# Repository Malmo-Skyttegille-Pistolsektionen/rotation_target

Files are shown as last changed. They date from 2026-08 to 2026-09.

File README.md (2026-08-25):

# Rotation Target

Software for running timed shooting programs on a rotating target system, built
by and for Malmö Skyttegille Pistolsektionen.

An ESP32-S3 board turns the targets face-on and edge-on to a shooting program
and plays the spoken range commands over an amplifier. A React web app — served
by the board itself over WiFi — starts and stops programs, follows the run live
over Server-Sent Events, and manages the stored programs and audio.

## ⚠️ SAFETY WARNING — READ BEFORE INSTALLING OR OPERATING

**This device moves steel on a live firing range, and it moves it on a timer.**
A target turns because a program said it was time, not because it can see who
is in front of it. It has no idea anyone is downrange.

- **The range's own safety rules and range commands govern the line. This
  software governs nothing.** A program running is not a range that is hot; a
  program stopped is not a range that is safe.
- **NEVER go downrange because the web app says the run has finished.** Confirm
  a cease-fire the way your range already requires — verbally, with firearms
  cleared and benched.
- **NEVER leave the device powered while people are forward of the firing
  line** unless your club has decided that is safe and knows what the targets
  do at power-up.
- **A target turning can injure somebody standing next to it.** Keep clear of
  the mechanism whenever the device is powered.

The targets rest **shown** at boot, deliberately: a target that turns of its own
accord when a board is powered is the failure this project is most concerned
with. That resting state can be changed to suit a target system wired the other
way round, but only over a USB cable, never from the web app — see
[Settings](https://malmo-skyttegille-pistolsektionen.github.io/rotation_target/settings/).

**Do not rely on this software to protect anyone.** It is a convenience for
running programs, not a safety device, and it has no interlock, no sensor, and
no way to know where people are.

**LIABILITY DISCLAIMER:** This project is provided as-is with absolutely no
warranty of any kind. The author(s) accept no responsibility or liability for
any injury, damage, or loss resulting from building, installing, modifying, or
operating this system. You build and use it entirely at your own risk.

---

## Documentation

Everything an operator needs is on the documentation site:

- **[Operator documentation](https://malmo-skyttegille-pistolsektionen.github.io/rotation_target/)**
  — wiring, connecting, running a program, settings, and what the status LED is
  telling you. This is the one to send a club member.
- **[Program editor](https://malmo-skyttegille-pistolsektionen.github.io/rotation_target/editor/)**
  — write and edit programs in a browser with **no device attached**, then
  download the file or open a pull request against this repository. Also useful
  for reading a shipped program without a board in front of you.
- **[Hardware and wiring](https://malmo-skyttegille-pistolsektionen.github.io/rotation_target/hardware/)**
  — what a target system has to do to work, the DB9 pinout, and the transistor
  that does the switching.

## Installing

Releases ship a pre-built firmware image; you do not need a toolchain to put it
on a board. See
[Connecting](https://malmo-skyttegille-pistolsektionen.github.io/rotation_target/connecting/)
for getting the device onto your network afterwards, and
[Settings](https://malmo-skyttegille-pistolsektionen.github.io/rotation_target/settings/)
for adapting a stock image to your own board — the target pin, its polarity,
the audio and LED pins and the device's name are all configurable on the
device, without rebuilding it.

## Target systems

- **[Eigenbrod TP2](https://eigenbrod-schiessanlagen.de/en/products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)**
  — what this was built against and what it runs on.

Nothing in the firmware is specific to that system. The board speaks no
proprietary protocol to the targets: it closes and opens **one circuit**, and
the target system's own electronics do the rest. Any system driven the same way
should work.

## Layout

| Directory | Holds |
|---|---|
| [`contracts/`](contracts/README.md) | The canonical API contract: OpenAPI for REST v2, AsyncAPI for SSE v2, the program schema |
| [`firmware/`](firmware/README.md) | The ESP-IDF firmware: target IO, audio, storage, REST + SSE server |
| [`webapp/`](webapp/README.md) | The React front end, embedded in the firmware's application image |
| [`resources/`](resources/README.md) | Shipped programs and audio clips flashed onto the device |
| [`docs/`](docs/) | The [decision log](docs/DECISIONS.md), [how releases are cut](docs/RELEASING.md), and the source of the documentation site |

## Contributing

Building, flashing, running it without a device, and the coding standards are
in [`CONTRIBUTING.md`](CONTRIBUTING.md).

## License

MIT — see the `LICENSE` file in each component directory.

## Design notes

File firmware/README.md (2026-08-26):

# Rotation Target Backend — ESP32 (ESP-IDF)

Native ESP-IDF firmware for Malmö Skyttegille Pistolsektionen's
[Eigenbrod TP2 rotation target system](https://eigenbrod-schiessanlagen.de/en/products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).
It runs shooting programs — turning the targets and playing the commands — and
serves the React webapp over REST and Server-Sent Events.

This is the ESP-IDF port of
[`rotation_target_backend_esp32_micropython`](https://github.com/Malmo-Skyttegille-Pistolsektionen/rotation_target_backend_esp32_micropython)
at its API v2 revision. Both speak the same contract; see
[`docs/adr/0001-esp-idf-port.md`](docs/adr/0001-esp-idf-port.md) for why the
port exists.

## Hardware

**ESP32-S3** with 16 MB flash and 8 MB PSRAM — an ESP32-S3-DevKitC-1 N16R8, or
the club's own REVOLVENOW Rev 1 board.

No pin is hardcoded: the target GPIO **and its polarity**, the status LED, and
the I2S pins are all `menuconfig` options, so a different board is a different
`sdkconfig` rather than a source edit.

See [`docs/HARDWARE.md`](docs/HARDWARE.md) for the wiring, the full option list,
the partition layout, and the esptool `--no-stub` quirk you will hit when
flashing these boards.

## Build, flash, test

```bash
git clone https://github.com/Malmo-Skyttegille-Pistolsektionen/rotation_target.git
cd rotation_target/firmware

idf.py set-target esp32s3          # FIRST clone only - see the warning below
idf.py menuconfig                  # optional: seed WiFi under "Rotation target backend"
idf.py build
idf.py -p /dev/ttyACM0 flash monitor
```

> ⚠️ **`idf.py set-target` and `idf.py fullclean` destroy `sdkconfig`** — the
> only copy of the WiFi credentials. Use **`idf.py reconfigure`** on a clone you
> have already built. Why, and how to keep the credentials out of the tree
> entirely, in [`CONTRIBUTING.md`](CONTRIBUTING.md).

> **`idf.py flash` uses esptool's stub loader, which fails on this board** and
> fails in a way that looks like bad flash. See
> [`docs/HARDWARE.md`](docs/HARDWARE.md) for the `--no-stub` invocation.

The shipped audio and programs live in the monorepo's sibling `resources/`
directory. The build reads them from there by default; point `RT_RESOURCES_DIR`
elsewhere to override.

The webapp is embedded in the **application image** when `../webapp/dist`
exists, so run `npm run build` in `webapp/` first — see
[*The seams*](../AGENTS.md#the-seams). Because it rides in the app slot, an OTA
updates it along with the firmware (#227); the shipped audio and programs are
still on the filesystem and still do not.

`idf.py flash` no longer touches what has been uploaded to the device: no image
is built for the `userdata` partition at all (#227), so there is nothing to
write over it. The app slot it writes carries the firmware, the web app and the
shipped audio together.

**`partitions.csv` is not a file to change casually** — a table change cannot
go out over the air and wipes NVS, so it costs a cable pass over every board.
See [*Changing the partition table*](CONTRIBUTING.md#changing-the-partition-table).

### WiFi

Credentials live in **NVS**, not in the firmware, so moving the device to a new
network does not need a rebuild. `idf.py flash` leaves the `nvs` partition
alone, so they also survive a firmware update.

If the device cannot join a network — out of the box, or because the range's
WiFi password changed — it brings up a **setup access point** and a captive
portal instead of sitting there unreachable:

1. Join `rotation-target-setup-XXXX` (password: `CONFIG_RT_SETUP_AP_PASSWORD`,
   default `rotationtarget`).
2. A setup page should open automatically; if not, browse to
   `http://192.168.4.1`.
3. Enter the network details. The device saves them and restarts.

The Kconfig `RT_WIFI_SSID`/`RT_WIFI_PASSWORD` values are only a first-boot
seed — leave them at the defaults and use the portal, or set them to skip it.
`sdkconfig` is gitignored either way, the same way the MicroPython backend kept
`wifi_credentials.py` out of git.

Once up, the device is at `http://rotation-target.local` (mDNS) or whatever
address it logs on boot.

### Host tests

The run state machine, the program JSON contract, the `stateUpdate` serializer
and the control lock all run on the build machine — no hardware, no sleeps:

```bash
cd host_test && cmake -B build && cmake --build build -j && cd build && ctest --output-on-failure
```

Add `-DRT_COVERAGE=ON` for gcov/gcovr coverage, or `-DRT_SANITIZE=ON` to build
the suites with ASan + UBSan:

```bash
cd host_test && cmake -B build-san -DRT_SANITIZE=ON && cmake --build build-san -j \
  && cd build-san && ctest --output-on-failure
```

CI runs both the plain and the sanitized build — the sanitizers force `-O1` and
change codegen, so a clean run of one is not evidence about the other. UBSan is
what catches signed-overflow in the duration and id arithmetic, which `-Wall`
cannot see.

Only `IDF_PATH` is needed (for ESP-IDF's copy of Unity), not the cross
toolchain.

### Lint

```bash
pre-commit run --all-files
```

`.clang-format` covers `main/`, `lib/rt_logic/` and `host_test/`. Vendored code
(`lib/psychic_http/`, `lib/arduinojson/`) and the repository's `resources/`
tree are excluded and must stay byte-identical to upstream — never reformat
them.

## API

[`docs/api-v2.md`](docs/api-v2.md) — REST under `/api/v2`, SSE at `/sse/v2`,
plus `GET /api/v2/diagnostics/info` for post-incident triage without a cable.
The canonical machine-readable contract is
[`../contracts/`](../contracts/README.md) — `openapi.yaml` for REST,
`asyncapi.yaml` for SSE, `program.schema.json` for the program document. A
change to any of them lands in the same PR as the firmware change it
describes.

## Layout

See [`docs/ARCHITECTURE.md`](docs/ARCHITECTURE.md) for the task model, the
locking rules and the storage layout.

| Path | Holds |
|---|---|
| `lib/rt_logic/` | Hardware-independent logic — the tested core |
| `lib/psychic_http/`, `lib/arduinojson/` | Vendored third-party |
| `main/` | The firmware: `io/`, `storage/`, `repositories/`, `executor/`, `net/` |
| `host_test/` | Unity suites for `lib/rt_logic/`, plus the CMake + CTest harness |
| `../resources/` | The shipped audio and programs (sibling directory) |

## Documentation

| Document | Covers |
|---|---|
| [`docs/api-v2.md`](docs/api-v2.md) | The REST + SSE contract, shared with the MicroPython backend |
| [`docs/HARDWARE.md`](docs/HARDWARE.md) | Boards, pin configuration, flashing, partitions |
| [`docs/ARCHITECTURE.md`](docs/ARCHITECTURE.md) | Task model, locking, storage layout |
| [`docs/QEMU.md`](docs/QEMU.md) | Running the firmware in the emulator, and what it does not emulate |
| [`docs/adr/0001-esp-idf-port.md`](docs/adr/0001-esp-idf-port.md) | Why this port exists |
| [`CONTRIBUTING.md`](CONTRIBUTING.md) | Workflow, tests, commit conventions |
| [`SECURITY.md`](SECURITY.md) | Threat model and reporting |

## Related

- [Frontend webapp](https://github.com/Malmo-Skyttegille-Pistolsektionen/rotation_target_frontend_webapp)
- [MicroPython backend](https://github.com/Malmo-Skyttegille-Pistolsektionen/rotation_target_backend_esp32_micropython)
- [Resources](https://github.com/Malmo-Skyttegille-Pistolsektionen/rotation_target_backend_resources) — programs, audio, API specs

## License

MIT. See [LICENSE](LICENSE).

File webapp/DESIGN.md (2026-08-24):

---
name: Rotation Target
description: Range-side control for a rotating pistol target — equipment that happens to have a screen.
colors:
  ink: "#111827"
  ink-body: "#213547"
  text-strong: "#374151"
  text-subtle: "#4b5563"
  text-muted: "#6b7280"
  surface: "#ffffff"
  surface-sunken: "#fafafa"
  surface-muted: "#f3f4f6"
  border: "#e5e7eb"
  border-strong: "#d1d5db"
  action: "#2563eb"
  action-deep: "#1d4ed8"
  accent: "#6366f1"
  accent-deep: "#4338ca"
  accent-tint: "#eef2ff"
  shown: "#16a34a"
  shown-tint: "#dcfce7"
  shown-text: "#14532d"
  go: "#15803d"
  go-deep: "#166534"
  stop: "#dc2626"
  stop-deep: "#b91c1c"
  stop-tint: "#fee2e2"
  stop-text: "#7f1d1d"
  warn: "#92400e"
  warn-tint: "#fef3c7"
  warn-border: "#fcd34d"
typography:
  # Eight steps, and every font-size in src/ is one of them. The ramp was
  # derived from what the app already shipped rather than imposed on it: the
  # sizes carrying real weight (0.85rem across 51 rules, 0.9rem across 37) were
  # simply never written down here, so the documented ramp and the CSS had
  # drifted apart in both directions.
  #
  # What was removed were the accidental near-duplicates - 0.7 beside 0.75,
  # 0.8 and 0.875 beside 0.85, and three components that each invented their
  # own `.title` size (1.05, 1.2, 1.25). Nothing moved by more than 0.15rem.
  display:
    fontFamily: "-apple-system, BlinkMacSystemFont, 'Segoe UI', Roboto, sans-serif"
    fontSize: "clamp(4.5rem, 24vw, 7rem)"
    fontWeight: 700
    lineHeight: 1
    fontVariation: "tabular-nums"
    usage: "The run screen's countdown, and nothing else."
  timer:
    fontFamily: "Inter, system-ui, Avenir, Helvetica, Arial, sans-serif"
    fontSize: "clamp(1.5rem, 5vw, 2rem)"
    fontWeight: 600
    lineHeight: 1.2
    usage: "The sticky timer that follows a run. Fluid on purpose - it has to stay readable on a phone held at arm's length and not dominate a laptop."
  headline:
    fontFamily: "Inter, system-ui, Avenir, Helvetica, Arial, sans-serif"
    fontSize: "1.5rem"
    fontWeight: 600
    lineHeight: 1.3
    usage: "Page headings, and the timeline's duration readout."
  title:
    fontFamily: "Inter, system-ui, Avenir, Helvetica, Arial, sans-serif"
    fontSize: "1.1rem"
    fontWeight: 600
    lineHeight: 1.4
    usage: "Section and card titles. The one step three components had each guessed differently."
  lead:
    fontFamily: "Inter, system-ui, Avenir, Helvetica, Arial, sans-serif"
    fontSize: "1rem"
    fontWeight: 500
    lineHeight: 1.5
    usage: "Controls that need to outweigh body text - a primary button, a card title in a dense list."
  bodyLarge:
    fontFamily: "Inter, system-ui, Avenir, Helvetica, Arial, sans-serif"
    fontSize: "0.95rem"
    fontWeight: 400
    lineHeight: 1.5
    usage: "Text the operator reads off a device at the range: table cells, form inputs, read-only values."
  body:
    fontFamily: "Inter, system-ui, Avenir, Helvetica, Arial, sans-serif"
    fontSize: "0.9rem"
    fontWeight: 400
    lineHeight: 1.5
    usage: "The default. Buttons, labels, most prose."
  small:
    fontFamily: "Inter, system-ui, Avenir, Helvetica, Arial, sans-serif"
    fontSize: "0.85rem"
    fontWeight: 400
    lineHeight: 1.5
    usage: "Supporting text under a control - hints, metadata, error detail. The most-used size in the app."
  label:
    fontFamily: "Inter, system-ui, Avenir, Helvetica, Arial, sans-serif"
    fontSize: "0.75rem"
    fontWeight: 600
    lineHeight: 1
    letterSpacing: "0.05em"
    usage: "Badges, group headings, tick labels. Anything set in caps."
rounded:
  sm: "4px"
  md: "6px"
  lg: "8px"
  xl: "12px"
  pill: "999px"
spacing:
  xs: "0.25rem"
  sm: "0.5rem"
  md: "0.75rem"
  lg: "1rem"
  xl: "1.5rem"
  xxl: "2rem"
components:
  button-default:
    backgroundColor: "{colors.surface}"
    textColor: "{colors.ink-body}"
    rounded: "{rounded.sm}"
    padding: "0.4rem 0.75rem"
    height: "var(--rt-control-height)"
    typography: "{typography.body}"
  button-primary:
    backgroundColor: "{colors.action}"
    textColor: "{colors.surface}"
    rounded: "{rounded.sm}"
    padding: "0.4rem 0.75rem"
    height: "var(--rt-control-height)"
  button-primary-hover:
    backgroundColor: "{colors.action-deep}"
    textColor: "{colors.surface}"
  button-destructive:
    backgroundColor: "{colors.surface}"
    textColor: "{colors.stop}"
    rounded: "{rounded.sm}"
    padding: "0.4rem 0.75rem"
  button-destructive-hover:
    backgroundColor: "{colors.stop-tint}"
    textColor: "{colors.stop}"
  button-go:
    backgroundColor: "{colors.go}"
    textColor: "{colors.surface}"
    rounded: "{rounded.lg}"
    padding: "0.75rem 1.5rem"
    height: "48px"
  button-stop:
    backgroundColor: "{colors.stop}"
    textColor: "{colors.surface}"
    rounded: "{rounded.lg}"
    padding: "0.75rem 1.5rem"
    height: "48px"
  input:
    backgroundColor: "{colors.surface}"
    textColor: "{colors.ink-body}"
    rounded: "{rounded.sm}"
    padding: "0.35rem 0.5rem"
    typography: "{typography.body}"
  badge-shown:
    backgroundColor: "{colors.shown-tint}"
    textColor: "{colors.shown-text}"
    rounded: "{rounded.md}"
    padding: "0 0.75rem"
    height: "36px"
  badge-hidden:
    backgroundColor: "{colors.stop-tint}"
    textColor: "{colors.stop-text}"
    rounded: "{rounded.md}"
    padding: "0 0.75rem"
    height: "36px"
  badge-neutral:
    backgroundColor: "{colors.surface-muted}"
    textColor: "{colors.text-strong}"
    rounded: "{rounded.md}"
    padding: "0 0.75rem"
    height: "36px"
---

# Design System: Rotation Target

## Overview

**Creative North Star: "Equipment, not software"**

This is range equipment that happens to have a screen. It is read standing up,
outdoors, in daylight, by someone who is about to run a live firing exercise and
has better things to look at than a user interface. Every visual decision
answers to that scene: grey by default, colour only where colour carries a
safety meaning, and type sized so the one number that matters can be read at
arm's length without walking to the phone.

The system is deliberately quiet. There is no brand expression competing for
attention, because the three signal colours — green, red, amber — have fixed
operational meanings and must be impossible to mistake for decoration. When a
surface looks plain here, that is the design working, not the design missing.

Density is medium and consistent: one control height for the whole app, one
breakpoint, one type ramp. The interface should feel like a well-labelled panel
of switches, where nothing moves unless the state moved.

**Key Characteristics:**

- Neutral greys carry structure; hue is reserved for state
- One control height (40px pointer, 44px touch) governs every row
- Numbers are tabular so a readout never reflows as it counts
- Flat at rest — depth is a response, not an ornament
- Legibility in daylight outranks visual interest, always

## Colors

A near-monochrome grey system with three signal hues that mean specific things,
plus a blue for the ordinary "do the thing" action.

### Primary

- **Signal Blue** (`#2563eb`): the ordinary confirming action — Save, Add,
  Create. It is the only blue in the system and never carries state meaning; a
  blue button is something you press, not something the target is doing.

### Secondary

- **Indigo** (`#6366f1`): "this is the one running." Marks the active series in
  the timeline and the time badge on the run board. Used as a border and a tint,
  never as a large fill.
- **Deep Indigo** (`#4338ca`): the same signal where it has to be readable as
  text — the active series title on its tinted ground.

### Tertiary

- **Amber** (`#92400e` on `#fef3c7`): the advisory register. Startup issues,
  "no delay armed", anything the operator should notice but which does not stop
  the exercise.

### Neutral

- **Ink** (`#111827`): the countdown readout, and nothing else. It is the
  highest-contrast value in the system and reserved for the highest-stakes
  number.
- **Body Ink** (`#213547`): default text.
- **Strong Grey** (`#374151`): badge text, table headers.
- **Muted Grey** (`#6b7280`): secondary and supporting text — the single most
  used colour in the app.
- **Border Grey** (`#e5e7eb`) / **Strong Border** (`#d1d5db`): dividers, card
  edges, control outlines.
- **Surface** (`#ffffff`), **Sunken** (`#fafafa`), **Muted** (`#f3f4f6`): the
  three grounds. Layering is done with these, not with shadow.

### Named Rules

**The Three Signals Rule.** Green means the target is shown, red means it is
hidden, amber means no delay is armed. No other element may use those hues for
any other purpose — not for a decorative accent, not for a chart, not for a
brand flourish. If a new state needs a colour and is not one of those three
things, it uses indigo or a grey.

**The One Family Rule.** The palette is the Tailwind scale, and only the
Tailwind scale. Two earlier families used to be mixed in — the Vite starter
purple (`#646cff`, never chosen, just the `npm create vite` default) and
Material's greens and reds on the timeline event boxes. Both are gone. The
purple mattered because it sits close enough to the accent indigo to look
intentional and far enough to look wrong beside it, which is the worst distance
for two colours to be.

**The Readable Signal Rule.** Signal colours are chosen for contrast, not for
brightness. White text sits on green-700 (`#15803d`), never green-600, because
white on green-600 measures 3.3:1 and fails AA. Any new coloured surface must
clear 4.5:1 for its text before it ships.

## Typography

**Body Font:** Inter (with system-ui, Avenir, Helvetica, Arial fallbacks)
**Readout Font:** the platform system stack (`-apple-system`,
`BlinkMacSystemFont`, `Segoe UI`, Roboto), used only for the countdown so the
digits render in the device's most familiar, most hinted numerals.

**Character:** plain, neutral, unstyled. The type is not doing expressive work;
it is doing legibility work. Weight and size carry the hierarchy, and there are
only three weights in the whole system.

### Hierarchy

- **Display** (700, `clamp(4.5rem, 24vw, 7rem)`, line-height 1): the countdown
  digits alone. Scales *up* with the viewport rather than down, and uses
  tabular numerals so the box does not resize as 10 becomes 9.
- **Headline** (600, 1.5rem): page titles.
- **Title** (600, 1.1rem–1.25rem): card and section headings, series titles.
- **Body** (400, 0.9rem): the workhorse. Table cells, descriptions, controls.
- **Label** (600, 0.75rem, 0.05em, uppercase): badge captions and field labels.
  Uppercase is the tell that something is a label and not content.

### Named Rules

**The Arm's Length Rule.** The countdown grows with the viewport instead of
shrinking with it. A phone held at the firing line is further from the eye than
a laptop on a desk, so `24vw` is the floor of the readout, not its ceiling.

**The Tabular Rule.** Any number that changes in place — countdown, elapsed
time, cumulative event time — is `font-variant-numeric: tabular-nums`. A
readout that jitters as its digits change is a readout nobody trusts.

## Layout

A single-column stack at every size, `1rem` page padding, `1rem` between cards.
Cards are full-bleed within that padding and do not have a max width; the
content is tables and timelines, both of which want the room.

**One breakpoint: 768px.** Below it, button rows become full-width columns,
event chips reflow, and tables switch to their compact presentation. Above it,
navigation tabs stop stretching to fill the bar. There is no tablet-specific
layout and there should not be one — the phone layout serves a tablet held in
two hands perfectly well.

**One control height.** `--rt-control-height` is the only global custom
property in the app: 40px for a mouse, 44px under `@media (pointer: coarse)` so
a gloved hand on the firing line gets the platform minimum tap target. Buttons,
selects, inputs and nav links all adopt it, which is what keeps a row of mixed
controls visually aligned.

Navigation is sticky at the top (`z-index: 30`). The run page is metres of
timeline on a phone, and the tabs have to stay reachable without scrolling back.

### Named Rules

**The No Nested Scroller Rule.** The document scrolls; panels do not. A flex
child with `overflow-y: auto` also computes `overflow-x: auto`, which silently
clipped the programs and audios tables off the right edge on a phone. Wide
content gets its own explicitly scrollable wrapper; layout containers get
`min-width: 0` instead.

## Elevation & Depth

**Flat at rest.** Surfaces separate by background tone and a hairline border,
not by shadow. This is a daylight interface: soft shadows wash out in sun and
cost more to composite on the device's embedded browser, while a 1px border at
`#e5e7eb` stays crisp in both.

Shadow is reserved for two jobs: things that genuinely float above the page,
and feedback that something responded to you.

### Shadow Vocabulary

- **Overlay** (`0 25px 50px -12px rgba(0, 0, 0, 0.25)`): modal dialogs only —
  the countdown and the confirmation. These really are above the page.
- **Response** (`0 2px 8px rgba(0, 0, 0, 0.1)`): hover and active feedback on
  an interactive card.
- **Lift** (`0 4px 12px rgba(0, 0, 0, 0.08)`): the running series. Neutral, not
  tinted — the indigo border already says "this is running"; a coloured halo
  under it only says "decorated".
- **Focus ring** (`0 0 0 3px <colour>/0.1`, or `outline: 2px solid #2563eb`
  with `2px` offset): keyboard focus. Never removed, never subtle.

### Named Rules

**The Flat-By-Default Rule.** A card gets a border, not a shadow. If you are
reaching for `box-shadow` on a resting surface, the answer is a tone change or
a border.

**The Neutral Elevation Rule.** Shadows are black at low alpha. A shadow tinted
to match its element's accent colour is decoration pretending to be depth.

## Shapes

A modest, consistent radius ramp and no other form language — no clipping, no
angles, no decorative geometry.

- **4px** — controls: buttons, inputs, nav links. The tightest radius, for the
  things you touch.
- **6px** — badges, chips, nested panels within a card.
- **8px** — cards and control boards.
- **12px** — modal dialogs, the largest surface and the largest radius.
- **999px** — pills, used sparingly for count indicators.

Borders are 1px for structure and 2px when the border itself is the signal (a
state badge, the active series).

### Named Rules

**The Side-Tab Ban.** No thick coloured border on one edge of a card. It is the
most recognisable tell of machine-generated UI, and this system says "warning"
with a tinted ground and a full hairline border instead.

## Components

### Buttons

- **Shape:** tight radius (4px), `--rt-control-height` tall, `0.4rem 0.75rem`
  padding, never wrapping (`white-space: nowrap`).
- **Default:** white ground, `#ccc` border, body text. The neutral majority.
- **Primary:** Signal Blue fill (`#2563eb`), white text, matching border;
  deepens to `#1d4ed8` on hover. One per view, at most.
- **Destructive:** white ground with a red border and red text (`#dc2626`),
  filling to `#fee2e2` on hover. Destructive actions are outlined, not filled —
  a solid red button is too easy to hit by accident on a touch screen.
- **Go / Stop (countdown only):** the two large 48px-tall filled buttons in the
  countdown dialog, green-700 and red-600, full-width on a phone. These are the
  only filled signal-coloured buttons in the app.
- **Focus:** `outline: 2px solid #2563eb` at `2px` offset on `:focus-visible`,
  on every interactive element without exception. The editor is driven from the
  keyboard as much as the mouse.

### Badges

- **Style:** 36px tall, 6px radius, `0 0.75rem` padding, a 2px border and a
  tinted ground, with an uppercase 0.75rem label beside the value.
- **Shown:** `#dcfce7` ground, `#16a34a` border, `#14532d` text.
- **Hidden:** `#fee2e2` ground, `#fca5a5` border, `#7f1d1d` text.
- **Time:** `#eef2ff` ground, `#6366f1` border, `#312e81` text.
- **Neutral:** `#f3f4f6` ground, `#e5e7eb` border, `#374151` text.

### Cards / Control Boards

- **Corner:** 8px. **Ground:** white on the page's `#fafafa`.
- **Border:** 1px `#eee`–`#e5e7eb`. **Shadow:** none at rest.
- **Padding:** `1rem`, with a `0.75rem` header rule above the content.

### Inputs

- **Style:** white ground, 1px `#ccc` border, 4px radius, `0.35rem 0.5rem`
  padding, `font: inherit` so they never drift from the body face.
- **Labels:** 0.75rem uppercase, stacked above the field with a `0.2rem` gap.
- **Focus:** the same 2px blue outline as buttons.

### Timeline (signature component)

The run page's series view is the one component with real domain personality.
Events render as compact chips — duration, command and cumulative time on one
line — reflowing four to five per row on a phone. The active series takes a 2px
indigo border and a neutral lift; the active event takes an indigo ring.

There is a time-scaled mode as well, but proportional widths are the wrong
default on a phone: a 1-second event inside a 30-second series is 3.3% of the
width, which is 11px at 390px wide. Auto mode chooses chips at narrow widths
for that reason.

### Dialogs

- **Shape:** 12px radius, `min(90vw, 420px)` wide, no border, the Overlay
  shadow.
- **Backdrop:** `rgba(0, 0, 0, 0.5)` with a 2px blur.
- **Content:** centred column, `2rem` padding (`1.5rem` on a phone), `1rem` gap.

## Do's and Don'ts

### Do:

- **Do** reserve green, red and amber for target shown, target hidden, and no
  delay armed. Anything else that needs colour uses indigo or a grey.
- **Do** put every interactive control at `var(--rt-control-height)` so mixed
  rows line up and touch targets stay at 44px on a phone.
- **Do** use `font-variant-numeric: tabular-nums` on any number that updates in
  place.
- **Do** give every focusable element a visible `:focus-visible` outline —
  2px solid `#2563eb`, 2px offset.
- **Do** check 4.5:1 contrast for text on any new coloured ground before
  shipping it. This system has already had ten failures found and fixed.
- **Do** give wide content (tables, timelines) its own scrollable wrapper
  rather than letting a layout container scroll.

### Don't:

- **Don't** put a thick coloured border on one side of a card.
- **Don't** put a resting shadow on a card. Use a border and a tone change.
- **Don't** tint a shadow to match its element's colour.
- **Don't** add `overflow-y: auto` to a flex layout container; it computes
  `overflow-x: auto` too and will clip content off the right edge.
- **Don't** put white text on green-600 (`#16a34a`) — 3.3:1. Use green-700.
- **Don't** introduce a fourth button style. There are four, and twelve files
  already redefine them; the next one should reuse, not add.
- **Don't** scale the countdown down on small screens. It is read from further
  away there, not closer.

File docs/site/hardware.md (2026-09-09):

# Hardware and wiring

This is what a target system has to be, electrically, before a board can drive
it — the thing a club member setting up a second device needs before anything
else on this site is useful.

## The interface: one circuit

The board does not speak any target system's proprietary protocol. It closes
and opens **one circuit**, over a DB9 connector, and the target system's own
electronics do the rest.

| DB9 pin | Function |
|---|---|
| 2 | Target control — shorted to ground to actuate the target system |
| 5 | Ground — the common return for pin 2 |

Electrically, the board does not close that circuit itself — a GPIO pin
supplies only tens of milliamps and should not meet the target system's
voltage directly. A transistor does the switching instead:

```mermaid
flowchart LR
    subgraph ESP["ESP32-S3"]
        GPIO["GPIO5"]
        GND["GND"]
    end

    R["1 kΩ"]
    Q["BC547B<br/>NPN · 45 V · 100 mA"]

    subgraph TS["Target system (DB9)"]
        P2["pin 2 — target control"]
        P5["pin 5 — ground"]
    end

    GPIO --> R --> Q
    Q -- collector --> P2
    Q -- emitter --> GND
    GND --- P5
```

A GPIO pin drives a 1 kΩ resistor into the base of a **BC547B** NPN
transistor, which does the actual switching. That transistor is rated
**45 V and 100 mA**, and it offers no galvanic isolation. Anything a target
system asks for beyond those limits — a mains-level signal, or an inductive
load like a relay coil — needs a relay or an opto-isolator of its own between
the DB9 connector and the load; it cannot be wired to pin 2 directly.

## What a target system has to do to work

Nothing in the firmware is specific to any one target system — it was built
against the [Eigenbrod TP2](https://eigenbrod-schiessanlagen.de/en/products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), but anything driven
the same way should work.

| Requirement | Why |
|---|---|
| Be actuated by a **contact closure** — two terminals shorted together | That is the entire interface. A system expecting a serial protocol, a proprietary bus or a mains signal needs hardware in between |
| Be **level-driven**, not pulse-driven | The firmware holds the line in one state for the length of an event. A system that toggles on each pulse would move on both edges |
| Have **two positions** — face-on and edge-on | The program vocabulary is show and hide. There is no intermediate angle to command |
| Take **one control line per group of targets you want to move together** | Each line is a *bank*. A bank is one contact closure and moves as one; a device drives up to eight |
| Be safe sitting **face-on** with no power | The targets rest face-on and stay there at boot, deliberately: somebody may be downrange when a board is powered, and a target that turns on its own can injure them |

## Target banks

A **bank** is one control line: one GPIO, one transistor, one DB9 circuit,
moving every target wired to it together. A device drives between one and
eight of them, lettered by position — **A, B, C…** — and A is the one the
diagram above shows. A club with one line of targets has bank A and nothing
else, which is what every device shipped so far is.

Banks exist so a range can be exposed a lane at a time: three lanes on three
banks can be shown one after another from a single program, where one line can
only turn all three at once.

Each bank is separate hardware. It needs **its own GPIO** and its own
transistor, and it carries **its own polarity** — whether a low level shows it —
because the resting state that has to be safe is a property of that bank's
wiring, not of the device. Adding one is therefore soldering first and
configuration second: wire the line, then add the bank in
[Expert mode](expert-mode.md) with the pin you wired it to, a name your
operators will recognise (`Vänster`, `Bana 3`), and the polarity that leaves it
resting where it should. The device adopts a new bank at its next restart.

Where the targets rest at boot is **one setting for every bank**, changed on
the serial console only: it protects somebody standing downrange, and that is
not a per-bank question.

Which level shows the targets, and the rest of the pin assignment, is a
configuration setting rather than a build setting now — but it is still decided
when a device is set up, not per range day. Full wiring detail, including the
supported boards and their `menuconfig` options, is in
[`firmware/docs/HARDWARE.md`](https://github.com/Malmo-Skyttegille-Pistolsektionen/rotation_target/blob/main/firmware/docs/HARDWARE.md)
in the repository.

**Optional peripherals**, each independently switchable off at build time: the
audio DAC that plays the range commands, and the [status LED](status-led.md).
A target that only turns, with no audio, is a supported configuration.

<!-- TODO: a photograph of the DB9 connector and the transistor as actually wired -->

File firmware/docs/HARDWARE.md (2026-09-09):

# Hardware

## Supported boards

The firmware targets **ESP32-S3** with 16 MB flash and 8 MB PSRAM. Two boards
are in use:

| Board | Module | Notes |
|---|---|---|
| ESP32-S3-DevKitC-1 N16R8 | ESP32-S3-WROOM-1 N16R8 | Development board. Has an onboard WS2812 on GPIO48. |
| REVOLVENOW Rev 1 | ESP32-S3-WROOM-1 N16R8 | The club's own board (open source hardware). Trigger outputs with selectable 3.3 / 5 / 12 V rails, Ethernet section, hand-fitted PCM5102A audio breakout on the Rev 1 prototypes. No onboard WS2812. |

Confirmed against real silicon with `esptool flash-id`: ESP32-S3 (QFN56)
rev v0.2, 16 MB **quad** flash at 3.3 V, embedded **8 MB octal** PSRAM. The
"flash type: quad" the eFuse reports is about the flash only — the R8's PSRAM
is octal, which is why `sdkconfig.defaults` sets `CONFIG_SPIRAM_MODE_OCT`.
Getting that backwards leaves PSRAM undetected at boot rather than failing
loudly.

## Configuration

**No pin is hardcoded.** Everything is a `menuconfig` option under
**Rotation target backend → Hardware**, so a different board is a different
`sdkconfig`, not a source edit.

| Option | Default | Meaning |
|---|---|---|
| `RT_TARGET_GPIO` | 5 | Drives the transistor that turns **bank A** |
| `RT_TARGET_ACTIVE_LOW` | y | Whether **low** shows bank A |
| `RT_RGB_LED_ENABLED` | y | Board has an addressable WS2812 |
| `RT_RGB_LED_GPIO` | 48 | Its pin |
| `RT_AUDIO_ENABLED` | y | Board has an I2S DAC |
| `RT_I2S_PORT` | 0 | I2S peripheral number |
| `RT_I2S_BCK_GPIO` | 10 | Bit clock |
| `RT_I2S_WS_GPIO` | 12 | Word select (LRCK) |
| `RT_I2S_DOUT_GPIO` | 11 | Data out → the DAC's DIN |

Defaults are the wiring the MicroPython backend used on this hardware
(`src/backend/config.py` in that repository). Note its "ESP32-C6" comments are
stale — the pin numbers beside them are correct, the chip name is not.

> ⚠️ **`RT_TARGET_ACTIVE_LOW` is a safety setting, not a preference.** It says
> which level *shows* the targets. On the prototype the GPIO drives a BC547B
> whose low state opens the connection. A board that buffers, inverts, or
> switches a relay directly needs it off — and if it is wrong, the boot state in
> `targets::init()` is inverted, so the targets face away when they should be
> face-on (D-31).

### Target banks

A device drives 1 to 8 banks, called **A** to **H** (D-41). Kconfig seeds bank A
only — a second bank is something a device is *told about*, over the API or the
serial console, and it lives in NVS beside the rest of the hardware
configuration. Every bank has its own pin, its own polarity and a display name.

| Bank | Suggested pin | Note |
|---|---|---|
| A | 5 | The stock target pin; `RT_TARGET_GPIO` |
| B–H | 6, 7, 8, 9, 13, 14, 15 | Adjacent on the DevKitC-1 header, all free |

Nothing forces those seven — any pin the validator accepts will do. They are
listed because they are contiguous on the header and none of them clashes with
the stock LED or I2S wiring.

### Pins the configuration refuses

`rt::validate()` refuses these outright rather than warning, because the
recovery from getting one wrong is a USB cable and a reflash.

| Pins | Why |
|---|---|
| 0, 3, 45 | Strapping — latched at reset; the board simply does not come up |
| 19, 20 | USB Serial/JTAG D-/D+ — the recovery path |
| 22–25 | Absent from the ESP32-S3 package |
| 26–32 | In-package SPI flash and PSRAM |
| **35–37** | The **octal** PSRAM's extra data lines on the N16R8 |
| **43, 44** | UART0 — the serial console |
| 46 | Input-only on many modules, so it cannot drive anything |

35–37 are the ones to know about; D-41 records why they were missed. That
leaves 22 output-capable pins after the stock five (target 5, LED 48, I2S
10/11/12) — comfortably more than eight banks need.

Disabling `RT_RGB_LED_ENABLED` or `RT_AUDIO_ENABLED` compiles the driver out
entirely rather than failing at runtime. A target that only turns, with no
audio, is a supported configuration: programs still run and the API still lists
clips, they simply do not play.

## Wiring (prototype)

| ESP32 pin | Connects to | Function |
|---|---|---|
| GPIO5 | DB9 pin 2, via 1 kΩ into a BC547B | Target control (bank A) |
| GND | DB9 pin 5 | Common ground |
| GPIO10 / GPIO12 / GPIO11 | PCM5102A BCK / LRCK / DIN | I2S audio |
| GPIO48 | onboard WS2812 (devkit only) | Status LED |

```mermaid
flowchart LR
    subgraph ESP["ESP32-S3"]
        GPIO["GPIO5"]
        GND["GND"]
    end

    R["1 kΩ"]
    Q["BC547B<br/>NPN · 45 V · 100 mA"]

    subgraph TS["Target system (DB9)"]
        P2["pin 2 — target control"]
        P5["pin 5 — ground"]
    end

    GPIO --> R --> Q
    Q -- collector --> P2
    Q -- emitter --> GND
    GND --- P5
```

The status LED, where fitted: **blinking red** while joining a network, **solid
red** once it has given up, **yellow** on the network but not serving yet,
**green** serving, **blue** on the setup portal's own access point. Yellow is
milliseconds wide on a healthy boot, so a device sitting on it means the network
is fine and the HTTP server is not.

## Flashing

### Large reads need `--no-stub`

**esptool's stub fails on `read-flash` above roughly 3 MB per transfer.** It
dies with `Packet content transfer stopped`. Measured on the DevKitC-1 over the
native USB port, esptool 5.3.1, reading from `0x0`:

| Transfer | Stub | Result |
|---|---|---|
| 1 MB | yes | works |
| 2 MB | yes | works |
| 3 MB | yes | works |
| 4 MB | yes | **fails** |
| 8 MB | yes | **fails** |
| 16 MB | yes | **fails** |
| 16 MB | `--no-stub` | works |

It is the *size* that decides it, not the address: where it dies is wherever
the transfer had got to. The threshold sits between 3 MB and 4 MB.

**The stub does not return bad data — it fails, or it is correct.** A 1 MB stub
read was compared byte for byte against the same range of a `--no-stub` dump of
the whole chip. The only differences were inside `nvs`, because esptool resets
the board between reads and the firmware writes NVS on boot. Everything else
matched exactly.

**So most work does not need `--no-stub`,** and the stub is roughly 15x faster
(1 MB in 5.9 s). Reach for it when reading at full-flash scale — taking a
backup image of a board, for instance:

```bash
esptool --port /dev/ttyACM0 --no-stub --baud 921600 \
  read-flash 0x0 0x1000000 flash_full_16MB.bin
```

**Writes are a separate question and are not covered by the numbers above.**
`write-flash` with the stub was measured good at 1.1 MB and at 10 MB on
2026-08-24, hash-verified, so `idf.py flash` is fine. A full 16 MB write with
the stub has not been tested. Until it is, a restore of a whole-chip image is
the one write worth doing with `--no-stub`, on the grounds that it runs when
something has already gone wrong.

```bash
# flash arguments are printed at the end of `idf.py build`
python -m esptool --chip esp32s3 --port /dev/ttyACM0 \
  --before default-reset --after hard-reset \
  write-flash --flash-mode dio --flash-freq 80m --flash-size 16MB \
  0x0 build/bootloader/bootloader.bin \
  0x8000 build/partition_table/partition-table.bin \
  0x1d000 build/ota_data_initial.bin \
  0x20000 build/rotation_target_backend.bin
```

**A failed large read presents exactly like a bad flash sector and is not one.**
Running the same read with and without `--no-stub` is the test that tells them
apart; chasing it as failing hardware, or as a cable problem, wastes a lot of
time.

> **This section has been wrong before.** It previously claimed the threshold
> was "about 256 KB" and that 512 KB and 1 MB reads failed — they do not. The
> rule survived unexamined because "always pass `--no-stub`" was cheap to obey,
> so nobody re-derived it. If you change these numbers, say what you measured
> and when.

### Ports

The boards expose two USB-C sockets. The **native USB-Serial/JTAG** one is USB
vendor `303a`; the **UART bridge** is `10c4` (CP2102) or `1a86` (CH343).

**Both can enumerate as `/dev/ttyACM*`** — the CH343 is a CDC device too — so
the device name does not tell them apart. The vendor does:

```bash
udevadm info -q property -n /dev/ttyACM0 | grep ID_VENDOR_ID
# 303a = native USB-Serial/JTAG
# 1a86 / 10c4 = UART bridge
```

**Which socket matters, and not symmetrically:**

| | native USB (`303a`) | UART bridge (`1a86`/`10c4`) |
|---|---|---|
| `ESP_LOG` output | yes | yes |
| **The interactive console** | **yes** | **no** |
| Flashing | yes | yes |
| Large `read-flash` | needs `--no-stub` | fine |

The console is the asymmetric one and it catches people out. `console.cpp`
writes with `usb_serial_jtag_write_bytes()`, so **the `rt>` prompt exists only
on the native USB socket.** On the UART bridge the log output still streams,
which makes the port look right — but every command typed there is silently
ignored. That covers `boot-targets` (#144), `wifi-scan` and `wifi-info`.

If a documented serial-only command appears to do nothing, check the vendor ID
before checking anything else.

With two boards connected, tell them apart by MAC — the kernel puts it in the
device name:

```
/dev/serial/by-id/usb-Espressif_USB_JTAG_serial_debug_unit_30:ED:A0:A8:AB:78-if00
```

While a board still runs MicroPython, its firmware claims the USB CDC endpoint
after every hard reset, so back-to-back esptool invocations are less reliable
than one long call; `--before no-reset --after no-reset` holds it in the
bootloader. This firmware does not use native USB and does not do that.

### Reflashing discards uploaded programs and audio

`idf.py flash` rewrites the LittleFS image, so anything a club uploaded to the
device goes with it. Use `idf.py app-flash` to update only the firmware and
leave the uploaded files alone.

The `nvs` partition survives either way, so the WiFi credentials and the
hardware configuration outlive a reflash.

## Partitions

16 MB, `partitions.csv`:

| Partition | Offset | Size | Purpose |
|---|---|---|---|
| `nvs` | 0x9000 | 24 K | WiFi credentials, calibration |
| `otadata` | 0xF000 | 8 K | Which OTA slot is active |
| `ota_0` | 0x20000 | 3 M | Firmware (~1 MB used) |
| `ota_1` | 0x320000 | 3 M | Second OTA slot |
| `storage` | 0x620000 | 9.75 M | LittleFS: shipped + uploaded audio and programs |
| `coredump` | 0xFE0000 | 128 K | Crash dump |

Sums to exactly 16 MB. Repartitioning a deployed device means a full erase, so
the slots are deliberately larger than currently needed.

OTA rollback is enabled and the app self-validates at the end of `app_main`,
but there is **no OTA endpoint yet** — the only way to write the second slot
today is `idf.py app-flash` over USB.

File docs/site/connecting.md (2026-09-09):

# Connecting

The board serves its own web app — there is nothing to install. But you can
only open it once the device is **on a network you are also on**, so that comes
first.

## Start with the LED

The [status LED](status-led.md) tells you which of two situations you are in,
before you try any address:

| LED | Situation | Go to |
|---|---|---|
| **Green** | On a network and serving | [Finding the device](#finding-the-device) |
| **Blinking red** | Still trying to join | Wait — it blinks once per attempt, about every 2.4 s |
| **Blue** | Gave up, and is now offering its own network | [The setup portal](#the-setup-portal) |
| **Solid red** | Out of attempts and not offering one either | See [Troubleshooting](troubleshooting.md) |

A device that has never been configured, or that has been moved to a site whose
WiFi it does not know, comes up **blue**. There is no address to find yet — the
network it should join does not exist from its point of view.

## The setup portal

A **blue** LED means the device is running a small access point of its own. Its
name follows the pattern `rotation-target-setup-XXXX`, where `XXXX` is unique to
that device, so two boards on the same site can be told apart.

Join that network from a phone or tablet. It is normally password-protected —
ask whoever set the device up if joining does not prompt for one. Once joined, a
captive-portal page should open by itself; if it does not, browse to
`http://192.168.4.1`.

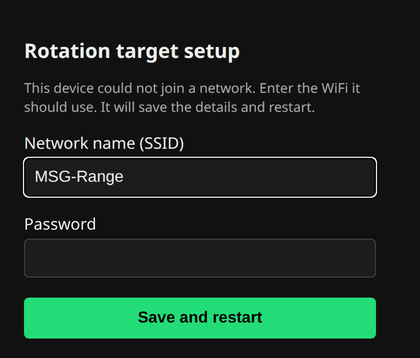
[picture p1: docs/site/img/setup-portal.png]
The setup portal, as it appears on a phone that has joined the device's own network


Enter the network name and password the device should use.

!!! important "Press the button on the device before saving"

    The device will not accept network details until somebody presses its
    **BOOT** button — the small button next to the USB sockets, marked `BOOT` or
    `FLASH` on some boards. Press it, then press **Save and restart**.

    If you save without pressing it first, the page says so and nothing is
    stored; press the button and save again.

    **Why:** the setup network's password is the same on every device and this
    project's source is public, so being *on* that network does not prove much.
    Pressing the button proves somebody is standing at the device — which is
    exactly what cannot be done from a car park. Without it, anyone in radio
    range of a device that has lost its network could point it at a network of
    their choosing.

    The press is good for about a minute, so there is no rush, and a press
    nobody remembers making cannot authorise anything later.

Once saved, the device restarts and joins that network the normal way — the LED
goes blinking red, then green.

From here it is on your network, and the rest of this page applies.

## Moving the device to a different network

If the device can no longer reach the network it knows — the club changed its
WiFi, or the board has been taken somewhere else — it gives up after about ten
seconds and raises the setup portal by itself. Nothing to do: wait for **blue**
and [configure it from there](#the-setup-portal).

The other case is: **the network it knows still exists, and you want it on a
different one anyway.** The device joins ours quite happily and never offers
the portal, so there is nothing to configure it through.

For that, use [Expert mode](expert-mode.md#wifi) — press the device's BOOT
button three times within ten seconds, and the web app offers the same form the
setup portal does. Saving stores the network; the device moves onto it when you
press [**Restart to apply**](expert-mode.md#restart-to-apply), and keeps
everything else: its programs, its clips, and its hardware settings.

**The ten-second hold below is the bigger hammer**, and it is now needed only
for handing a board to another club, or for a board that has to forget the
network built into its firmware. It throws away more than the network.

To do that, **hold the BOOT button for ten seconds**.

| While you hold | LED | Meaning |
|---|---|---|
| 0–3 seconds | unchanged | Nothing has happened yet |
| after 3 seconds | **white** | It is counting. Let go now and nothing is changed |
| after 10 seconds | restarts | Done |

It comes back up **blue**, offering its setup portal, exactly like a board that
has never been configured.

!!! warning "What a ten-second hold erases"

    - **Every network it knows**, including the one built into its firmware —
      which is the point, otherwise it would simply rejoin ours.
    - **Its hardware settings**: pin numbers, hostname and display name go back
      to the defaults, so it will answer to `rotation-target.local` again.

    **Your programs and audio clips are kept.** Anything uploaded to the device
    stays on it, including through a change of owner — that is a separate thing
    from which network it is on, and it may be the only copy.

If you have a USB cable and a serial terminal, `factory-reset` at the device's
console does the same thing and says what it is about to do first.

## Finding the device

Join the same WiFi the device is on, then open its address.

It advertises itself over mDNS, so on most phones, tablets and laptops the
address is just its hostname:

```
http://rotation-target.local
```

If that name does not resolve — some routers and most guest networks block
mDNS — find the device's IP address instead, for example from the router's
client list, and open `http://<that address>` directly. The address is also
shown on the app's own Settings page, beside the server URL, which is the
easiest way to read it out to somebody else once you are in.

The app opens on the Run page:

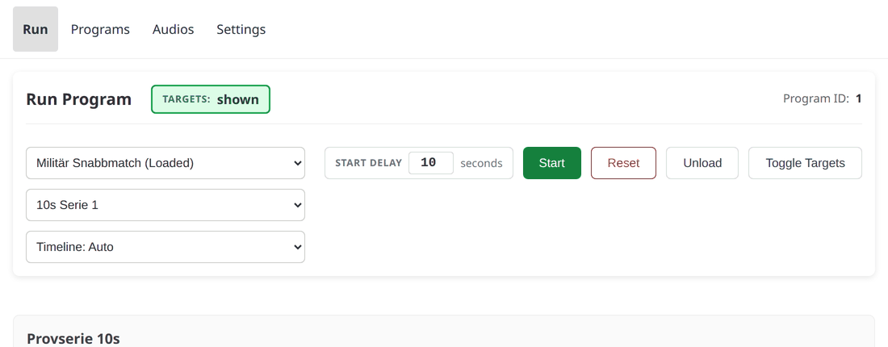
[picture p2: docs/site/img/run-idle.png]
The Run page with nothing loaded


## Editing programs without a device

Programs can also be written on a laptop with no board involved at all, using
the [program editor on the web](https://malmo-skyttegille-pistolsektionen.github.io/rotation_target/editor/)
— see [Writing your own program](writing-a-program.md).

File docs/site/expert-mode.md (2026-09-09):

# Expert mode

Everything that can stop the device working lives here, and nothing else does.

Most clubs never open this page. The settings on it are the ones set once, when
a board is first put together or moved somewhere new — and getting one wrong
does not produce a warning, it produces a device that no longer answers.

## Getting in

**Press the BOOT button on the device three times within ten seconds.** It is
next to the USB sockets and may be marked `FLASH`. An **Expert mode** tab
appears in the web app and stays for five minutes; press three times again for
a fresh five.

Three presses rather than one so it cannot happen by accident, and a button
rather than a password because the thing being established is that **somebody
is standing at the device**. That is not something anyone can do from across
the range, at any distance, with any credential — which is the whole point.

!!! note "It will not open during a run"

    A program that is running holds the window shut. Reconfiguring the machine
    and operating it are different jobs, and these settings only take effect
    when the device restarts anyway. Stop the run first.

If the tab is not there, nobody has pressed the button recently. If it vanishes
while you are typing, the five minutes ran out — press three times again and
carry on.

## Restart to apply

**Nothing on this page takes effect until the device restarts**, and nothing on
it restarts the device by itself. Each section has a plain **Save**, which
stores the change; the device carries on doing what it was doing.

**Restart to apply** appears beside the *Expert mode* heading whenever the
device is holding a setting it is not yet running, and applying everything is
one press of it. So a pin, the hostname and the network can all be corrected in
the same sitting, and the device goes down once instead of three times.

!!! note "The page loses contact while it restarts"

    A few seconds, then reload. If a network change was among what you saved,
    reload at the device's name on the *new* network — and if it cannot join
    that one, it raises its own setup network (`…-setup-XXXX`) and waits there,
    which is [the way back](connecting.md#the-setup-portal) rather than a fault.

The button stays after the five-minute window lapses, and the sections do not:
what the window authorises is the *change*, and this only applies one already
made. **Settings** says the same thing in one line, so somebody who did not make
the change still finds out about it.

It will not restart during a run. Stop the program first.

## WiFi

Which network the device joins. The same form as
[the setup portal](connecting.md#the-setup-portal), because it is the same job:
pick a network from the list, or type the name of one the scan did not find,
and give the password.

**This is the answer to "the network it knows still exists, but I want it
somewhere else."** Before this existed, the only way was to erase everything
the device knew and let it fall back to its setup portal — see
[moving the device](connecting.md#moving-the-device-to-a-different-network),
which is still the route when the board cannot reach *any* network it knows.

**Save** stores the network and nothing more: the device stays on the network
this page is served over, so a mistake here is still fixable from the page that
made it. It moves when you press **Restart to apply**, which is where the
warning above about losing contact applies.

Nothing you have uploaded is affected. Programs and clips are a separate thing
from which network the device is on.

**Rescan networks** runs a fresh scan. It takes a couple of seconds during
which the device's radio is off its own channel, so the page may pause — that
is the scan, not a fault.

**For a hidden network**, leave the list alone and type the name. A hidden
network never appears in a scan, so the list cannot offer it.

## Hardware

Which pins this board uses, what it calls itself, and how it joins the network.
Wrong values here are the ones whose way back is a USB cable:

- A **wrong pin** drives nothing, and one of the pins the device refuses would
  stop it booting at all — which is why it refuses them.
- A **wrong hostname** changes the name the device answers to, so the web app
  stops being reachable at `rotation-target.local`. Worse than a wrong pin,
  which at least leaves the app up to fix it from.

**Nothing here takes effect until the device restarts**, and the page says so
when a saved value is not yet in use — then **Restart to apply** at the top of
the page. A change that appears to have done nothing is how somebody ends up
reflashing a working device.

### The target banks

**Targets** is a table, one row per [bank](hardware.md#target-banks) — one
control line each, lettered by position:

| Column | What it is |
|---|---|
| **Bank** | The letter, A first. It is the row's position, not a stored value, so removing a bank re-letters the ones after it |
| **Name** | What operators see on the Run page — `Vänster`, `Bana 3`. Display only, at most 16 characters, and may be left empty |
| **GPIO** | The pin this bank's transistor is wired to. Every bank needs its own, distinct from the LED's and the three audio pins |
| **Shown when low** | Whether a low level shows *this* bank. Per bank, because the resting state that has to be safe is a property of that bank's wiring |
| **Pad now** | The level actually on the pin, read back rather than remembered. It answers "is the firmware driving this" without a multimeter |

**Add bank B** appends the next letter, up to eight — the most this firmware
drives. A new row starts with **no GPIO**; Save waits until every row has one,
because GPIO 0 is a pin the device refuses and a row cannot be left holding a
value that would come back an error.

Only the **last** bank can be removed, and **bank A never can**: the letter is
the position, so removing B on a four-bank device would silently re-aim C and D
at the wrong lanes. Remove them from the end and add them back.

A row whose values differ from the compiled defaults is marked **changed**, the
same way every other setting on this page is, so **Reset to defaults** says
what it would undo.

A bank you add is only configuration; the line still has to be wired, and the
device adopts the new count when it restarts.

**Where the targets rest at boot** is shown but not editable, and it is **one
setting for every bank**. Which position is safe at rest is a property of the
target system, so it has to be configurable — but it is also what protects
somebody standing downrange when a board is powered, so it changes only from
the serial console with a cable attached.

## Troubleshooting

One zip file holding the device's own details and, if it has crashed, the crash
dump — the thing to attach to a message when a board has come back from a range
day behaving oddly.

!!! warning "A crash dump can contain the WiFi password"

    It is a copy of the device's memory at the moment it failed. Send it to
    somebody you would tell the password to.

That is why it is behind the button press, and it is *only* behind the button
press: [the control lock](settings.md#control-lock) does not block it. Collecting a
fault report is a read, it interferes with nobody, and the person most likely
to want one during a competition is whoever is not driving.

[Sending a fault report](troubleshooting.md#sending-a-fault-report) has the
steps.

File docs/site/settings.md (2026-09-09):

# Settings

The Settings tab holds two different kinds of thing, and it is worth knowing
which is which before changing anything:

- **Browser settings** live in the browser you are using. Another phone or
  tablet at the same range keeps its own, and clearing site data resets them.
- **Device settings and readouts** come from the board itself, and are the
  same for everyone looking at it.

| Section | Kind | What it is |
|---|---|---|
| Server Base URL | browser | Which device this browser talks to |
| Address | device | The address the device says it is reachable on |
| Control lock | device | Whether control is open to everyone or needs a login |
| Start delay | browser | Seconds counted down before a run starts |
| Startup Issues | device | What the device could not read when it booted |
| Storage | device | How much room the flash partitions have |
| WiFi | device | Which network it is on, and how good the link is |
| About | device | What firmware and web app this is, and exactly which build |

Nothing on this page can stop the device working. The settings that can —
which network it joins, which pins it drives, and the crash dump download —
are on [Expert mode](expert-mode.md), behind a button press on the board
itself.

**One line can appear at the top:** *Configuration saved but not applied;
restart from Expert mode.* It means somebody changed a setting on that page and
the device is still running what it started with. The change is not lost and
nothing is broken — it needs
[**Restart to apply**](expert-mode.md#restart-to-apply), which is on that page
whether or not the five-minute window is still open. It is here so that the
next person to pick the device up finds out, rather than being surprised by it
at the next power cycle.

**Target banks are configured there too.** How many lines this device drives,
what each is called and which pin it is on is Expert-mode work —
[the bank table](expert-mode.md#the-target-banks) — because a wrong pin is one
of the settings whose way back is a USB cable. What you see on the Run page —
the lettered strip and the per-bank buttons — follows from it, and needs
nothing set here.

## Server Base URL

Normally there is nothing to do here — the app talks to whatever served it.
It matters when the app is being run from somewhere other than the device
(during development, or from a copy on a laptop) and needs pointing at a board.

## Address

What the device reports as its own address. If it says the device has no
address, it is serving its own access point instead of being on a network —
see [the setup portal](connecting.md#the-setup-portal).

## Control lock

Two states:

- **Full public access** — anyone who can reach the page can control the
  device. This is the default, and it is usually what a range wants: no
  password to pass around while people are shooting.
- **View only** — the page still shows what is happening, but starting,
  stopping, uploading and deleting all require a login.

Turning it on asks for a password to set. From then on this browser holds a
token; **Login** on another browser asks for that password again.

The password protects against the accidental rather than the determined: the
device is on the range's own network, and the traffic is plain HTTP.

## Start delay

Covered under [starting a run](running-a-program.md#starting) — it is here as
well because it is a setting, and the two controls write the same value.

## Startup Issues

What the device could not read when it booted: a program file that does not
parse, a clip whose header is not a WAV it can play. The list is bounded and
drops the oldest, so a device with many bad files shows the most recent ones.

An empty list is the normal state and says the boot scan read everything.

## Storage

Partition sizes. Note the note: **size only — the device cannot report what is
used here** for some partitions, so a figure being absent is not a fault.

The one to look at is **`userdata`**. It holds what has been uploaded to the
device — programs and audio clips — and nothing else. Everything that ships
*with* the device is inside the firmware itself, so the shipped set growing can
no longer eat the room for yours, and updating the device cannot touch what you
put on it.

`ota_0` and `ota_1` are the two copies of the firmware. One is running and the
other is where an update is written, which is what lets a bad update be undone.
Seeing one of them nearly empty is normal on a device that has never been
updated.

## WiFi

Which network the device joined, how strong the signal is, the address it is
reachable at, and the MAC address a router lists it under. All of it is a
readout — nothing here changes anything.

**Which network matters, not just that there is one.** A device remembers the
network it was set up on *and* the one its firmware was built for, and joins
whichever it can see. A board that has been to two places may be on either, and
this is where you find out which.

**Signal** is shown as bars and as a number in dBm. The number is negative and
closer to zero is stronger — around −50 is excellent, −70 is workable, and
below about −80 is where a device starts dropping off the network. It is the
figure to watch while moving a board around looking for somewhere to mount it.

If it says **no network has been saved**, nobody has set this device up here.
It is running on whatever network its firmware was built for, which cannot be
read back or changed without rebuilding it — so if it is working, it is working
by luck of being in the right building.

To *change* the network, see [Expert mode](expert-mode.md#wifi). It is a
once-per-site decision behind the button press on the board, which is why it is
not on this page.

## About

**App** is the version of the page you are looking at. **Device** is the
firmware's. One version number covers firmware, web app and shipped content,
and the web app is part of the firmware image itself — so a page served *by*
the device always matches it, however the device was updated.

That includes an update sent over the network, which used to be the awkward
case: it replaced the firmware and left the web app behind, so a device could
serve a page older than the firmware running it until somebody flashed it over
USB. That cannot happen any more. The shipped programs and audio are still
stored separately and are still not updated over the network.

So a mismatch now means one thing: **this page did not come from that device.**
A development build, or a copy served from a laptop, pointed at a board built
from a different commit.

A hard reload will not help. The browser is showing the version it was given;
the two really are different.

**Modified build** beside the device version means the firmware was built from
a working copy with uncommitted changes. On a board flashed from a release that
should not appear; on a board somebody has been developing against, it is
normal.

### Build details

**Build details** opens a table naming exactly which build this is: the commit,
when it was built, which branch it came from, the ESP-IDF version, and
fingerprints of the web app and audio it was built with.

None of it is worth reading day to day. It exists for one situation: **a board
that has come back from a range day behaving oddly.** "Which firmware is this"
is answerable from the version alone; "which commit, built where, with which
audio set" is not, and those are the questions that get a fault diagnosed.

**Copy** puts the whole block on the clipboard, ready to paste into a bug
report — which is the only thing it is for. If your browser refuses (some do on
a plain `http://` address, which is what the device serves), the text appears
below instead so you can select it by hand.

## Troubleshooting

The crash dump download has moved to [Expert mode](expert-mode.md#troubleshooting).
It is behind the device's BOOT button because a crash dump can contain the WiFi
password, and everything behind that button is now on one page rather than
appearing and disappearing on this one.

[Sending a fault report](troubleshooting.md#sending-a-fault-report) has the
steps and what it means for who you send it to.

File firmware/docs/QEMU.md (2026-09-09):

# Running the firmware in QEMU

The firmware boots unmodified in Espressif's QEMU fork, serves the real REST
API, the real SSE stream and the real webapp out of the real LittleFS image,
and answers on `http://localhost:8080`. That makes a browser session or an E2E
suite possible without a board on the desk, against the same code that ships —
not a mock.

```sh
. <esp-idf>/export.sh
firmware/scripts/run-qemu.sh
# then: http://localhost:8080   (Ctrl-A X quits QEMU)
```

The script installs `qemu-xtensa` on first use
(`python "$IDF_PATH/tools/idf_tools.py" install qemu-xtensa`), builds the QEMU
profile into `build-qemu/`, merges the flash image and boots it. `--build-only`
stops after the build; `--headless` boots with no terminal attached;
`--port N` changes the host port.

Boot to serving takes about two seconds of guest time.

## How it differs from the board

QEMU emulates no WiFi radio, so the network comes up over the OpenCores
Ethernet MAC the emulator maps onto the EMAC register window. That is the whole
of `CONFIG_RT_NET_OPENETH`: `main/net/eth_mgr.cpp` is compiled instead of
`main/net/wifi_mgr.cpp`, both implementing `main/net/net_mgr.h`. With the WiFi
translation unit out of the build, the setup portal and the NVS credential
store are not linked in at all — there is nothing to provision, because SLIRP
hands the guest 10.0.2.15 over DHCP.

The rest of the profile is `sdkconfig.defaults.qemu` layered on
`sdkconfig.defaults`: audio and the RGB LED off, PSRAM addressed as quad (see
below), everything else — 16 MB flash, the partition table, the socket
budget — exactly as the board has it.

## What works

| | |
|---|---|
| REST `/api/v2/*` | All of it, including the control lock and `diagnostics/info` |
| SSE `/sse/v2` | `stateUpdate` and `heartbeat`, real timing |
| The webapp | Served from LittleFS at `http://localhost:8080` when `webapp/dist` exists at build time, `.gz` assets included |
| LittleFS | Mounts the flashed image: 7 shipped programs, 77 audio entries, uploads |
| Executor timing | Tracks host wall-clock — `tickerMs` advances once a second and series boundaries land where the program says |
| Watchdogs | Disabled by the runner (`wdt_disable`); nothing feeds them under emulation |

## What does not work

- **Audio is silent.** There is no I2S peripheral to emulate, so
  `RT_AUDIO_ENABLED` is off and `main/io/audio.cpp` takes its no-op path.
  Programs still run, and the API still reports the audio catalogue.
- **The RGB LED does nothing.** No RMT peripheral; `RT_RGB_LED_ENABLED` is off
  and `main/io/rgb_led.cpp` takes its no-op path.
- **GPIO writes are discarded.** The target pin is driven exactly as on the
  board, but nothing in the emulator observes it and a pad readback does not
  reflect a write. Where the API says the banks are comes from the executor,
  not from the pin — `diagnostics/info` shows `banks[].padLevel: 0` throughout.
- **mDNS is not reachable from the host.** The responder runs and answers
  inside the guest, but SLIRP does not carry multicast to the host — use
  `localhost:8080`, never `rotation-target.local`.
- **CORS by device IP does not match.** The allowlist knows
  `rotation-target.local` and the guest's own 10.0.2.15; a browser on
  `http://localhost:8080` sends that origin instead. Same-origin requests need
  no CORS headers, so the bundled webapp is unaffected; a Vite dev server
  against the emulator needs `CONFIG_RT_DEV_ORIGIN`.
- **`GET /api/v2/version` reports `0.0.0`.** The app version is a raw
  `git describe`, which that endpoint's strict parse rejects. Not a QEMU
  artefact — the board does the same until versioning lands.
  `diagnostics/info` reports the describe string verbatim.

Noise that is expected on every boot and safe to ignore:

```
E esp_eth: esp_eth_ioctl(533): add mac address to filter not supported
E esp_netif_lwip: Failed to add multicast filter for IPv4
W opencores.emac: emac_opencores_isr_handler: RX frame dropped (0x14)
W rtcinit: o_code calibration fail
```

The OpenCores MAC has no multicast filter, so lwIP's IGMP setup fails; a frame
or two is dropped while the DMA rings fill; the RTC calibration has nothing to
calibrate. Nothing downstream depends on any of it.

## Two things the emulator gets wrong, and what the runner does about them

**PSRAM is addressed as quad, not octal.** The board is an N16R8 and
`sdkconfig.defaults` says `CONFIG_SPIRAM_MODE_OCT`. Under qemu-xtensa 9.2.2 the
octal model segfaults the emulator inside `psram_transfer()`
(`hw/misc/ssi_psram.c`) during the driver's init transfer — deterministically,
right after `boot: Loaded app from partition` and with no guest output at all,
so it reads as a silent hang. `sdkconfig.defaults.qemu` therefore selects
`CONFIG_SPIRAM_MODE_QUAD` at 40 MHz. The pool is the same 8 MB and nothing
above the driver can tell the difference. Revisit when the emulator's octal
model is fixed.

**PSRAM size must be passed explicitly.** `idf.py qemu` hardcodes `-m 32M`. At
that size the guest's PSRAM claims the entire external-memory virtual address
range:

```
W esp_psram: Virtual address not enough for PSRAM, map as much as we can. 31MB is mapped
E mmap: esp_mmu_map(479): no such vaddr range
E partition: load_partitions returned 0x105
ESP_ERROR_CHECK failed: esp_err_t 0x105 (ESP_ERR_NOT_FOUND)
```

Every flash mmap after PSRAM init fails and the app aborts in
`nvs_flash_init()`. The runner passes `-m 8M`; override with `QEMU_PSRAM_MB`
for a different module.

Because neither of those can be expressed through `idf.py qemu`, the runner
builds with `idf.py` but invokes `qemu-system-xtensa` directly, merging the
flash image with the same `esptool merge-bin` call `idf.py qemu` would have
used. It also omits the eFuse drive `idf.py qemu` always attaches — that image
describes a chip revision v0.3 part, and on v0.3 the PSRAM driver runs MSPI
timing tuning, another path the emulator faults in. Without the drive the eFuse
reads back as v0.0 and the tuning is skipped.

## Running it in CI

`run-qemu.sh --headless` is the CI shape: no TTY needed, serial goes to stdout.

The `firmware boot smoke` job in `.github/workflows/firmware-build.yml` is the
worked example: build, boot, poll, assert `/api/v2/version`, `/api/v2/programs`,
one SSE `stateUpdate` and the API-only `GET /` 404.

```sh
firmware/scripts/run-qemu.sh --build-only
firmware/scripts/run-qemu.sh --no-build --headless > qemu.log 2>&1 &
# poll http://localhost:8080/api/v2/version until it answers, then assert
```

`--no-build` is what keeps the boot half honest: without it the backgrounded
run re-runs a no-op `idf.py build` first, and a boot timeout would be timing
the build. No `idf_tools.py install qemu-xtensa` either - `espressif/idf:v6.0.2`
already ships qemu-xtensa 9.2.2 on `PATH`, so there is nothing to cache; the
runner's install-on-first-use branch is for a bare IDF checkout.

The flag matters: interactive runs get `-serial mon:stdio`, and QEMU quits the
instant that stdin reports EOF — which is exactly what a CI runner or a
backgrounded shell hands it. Headless runs get `-serial file:/dev/stdout` and
`-monitor none` instead, and never read stdin at all.

## Not for real hardware

`CONFIG_ETH_USE_OPENETH` is documented upstream as "for use with QEMU… not
supported when running on a real chip". A build with `CONFIG_RT_NET_OPENETH=y`
will not reach a network on the board; it is a simulator profile and nothing
else. The board build is the default and is untouched by any of this.

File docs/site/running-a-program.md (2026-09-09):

# Running a program

## Loading

Pick a program from the dropdown on the Run page. Choosing one **loads** it —
it does not start it. The device confirms what it has loaded before the page
lets you do anything with it; a program picked but not yet confirmed leaves
Start disabled for a moment.

A program is a series of **series** — a match's separate strings of fire, for
example — each with its own targets and events. If the program has more than
one, a second dropdown picks which series to run first; skip ahead to a later
one at any point (see [Skipping](#optional-series-and-skipping) below).

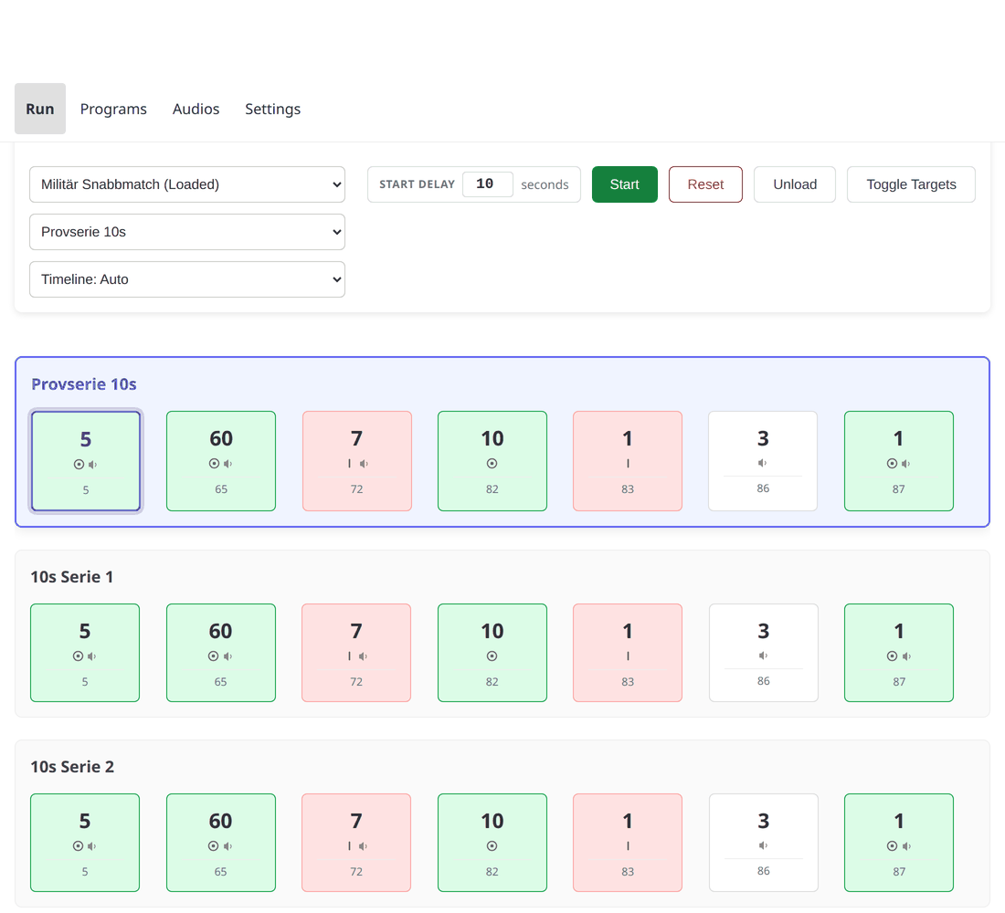
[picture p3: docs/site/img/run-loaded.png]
The Run page with a program loaded


## Starting

**Start delay** sets how many seconds count down before the program actually
starts — 0 starts it at once. It is saved in the browser you set it in, so
another phone or tablet at the same range keeps its own value.

With a delay set, Start opens a countdown with its own **Start Now** (skip the
rest of the wait) and **Cancel** buttons. The countdown is cancelled
automatically if the device's loaded program changes underneath it — another
tab or device on the range changed something — and a message explains why.

Once running:

- **Pause** stops the run and keeps its exact position, down to the
  millisecond — a resume with no delay set picks up from there, not from the
  start of the series.
- **Reset** rewinds to the start of the *current* series (the series stays
  selected; only its position resets). Only available while paused.
- **Unload** clears the loaded program entirely. Offered even mid-run: the
  device refuses it while a program is running and explains why, so Pause is
  the way out of that refusal.
- **Toggle Targets** flips the targets show/hide directly, independent of any
  program — useful for checking the wiring works at all.

On a device with more than one [target bank](hardware.md#target-banks), the
`TARGETS` badge at the top of the page becomes a **strip**: one cell per bank,
lettered A onward, green for shown and red for hidden, with the bank's name
under the letter on a screen wide enough for it. So a range exposed one lane at
a time is one glance to read, and a bank that did not move is visible rather
than averaged away.

The controls follow it. Instead of one **Toggle Targets** button there is a
**Targets** group: tapping a lettered cell flips **that bank alone**, and
**Show all** / **Hide all** move every bank together. A one-bank device — which
is most of them — keeps the single badge and the single button, unchanged.

Until the device has said where the targets are, the badge reads `-` rather
than guessing.

## The timeline

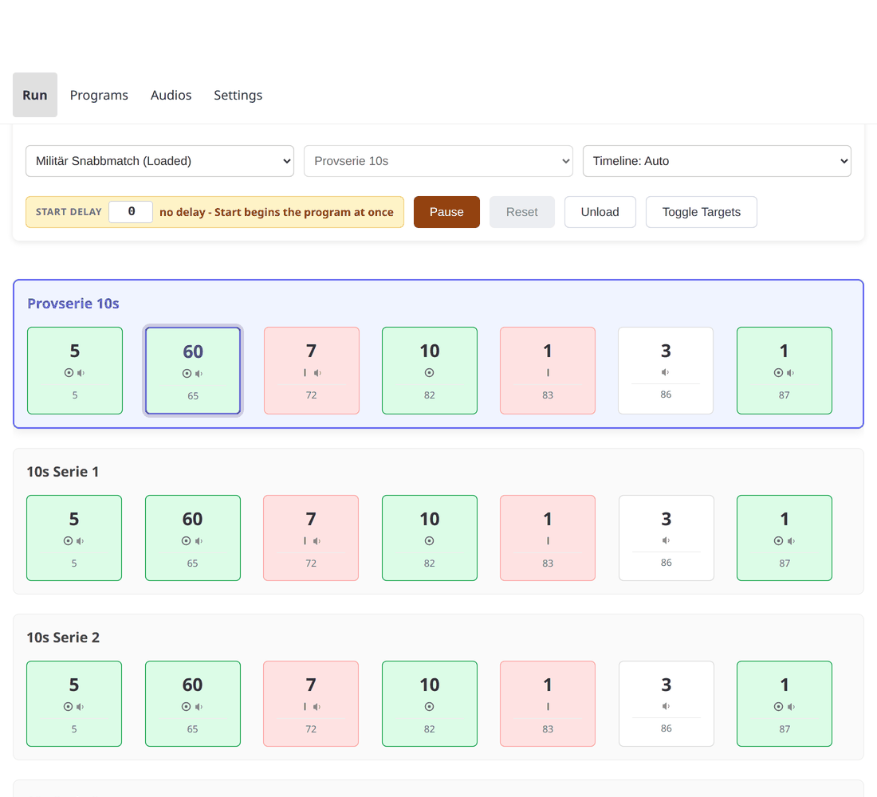
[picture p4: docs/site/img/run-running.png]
A run in progress


The Run page shows every series and event in the loaded program, and tracks
the run live as it plays:

- Each event shows its duration, whether it shows or hides the targets, and
  whether it plays a range command over the amplifier.
- Point at (or tap) an event to see its full detail — including which audio
  clips it plays, named rather than by number.
- The running series scrolls into view automatically as the run reaches it.

Three display modes are available from the dropdown beside the program
picker: **Auto** picks the layout that suits the loaded program, **Event-based**
draws events as a fixed-width sequence, and **Time-scaled** draws them
proportional to their actual duration, with a moving cursor showing exactly
where the run is right now.

## Optional series and skipping

Some series are marked **optional** — a warm-up string, for example — and
carry a badge on the timeline to say so. While the run is sitting at an
optional series (not while it is playing), a **Skip** button on that series
moves straight to the next one without running it.

The series dropdown reaches every series directly, at any time the program is
not running, in case the run needs to jump further than one step — but
skipping mid-run is not offered: **Pause** is how a series in progress gets
cut short.

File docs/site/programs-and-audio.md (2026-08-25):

# Programs and audio

Everything the device runs is stored on the device: the programs, and the
spoken range commands they play. Both are managed from the web app, and both
come in two kinds — **shipped** with the firmware, and **uploaded** afterwards.

The difference matters because shipped content cannot be changed or deleted
from the web app. It is part of the firmware image, so a new firmware brings a
new set; nothing done at the range can remove it. Uploaded content is yours to
add, replace and delete.

## Programs

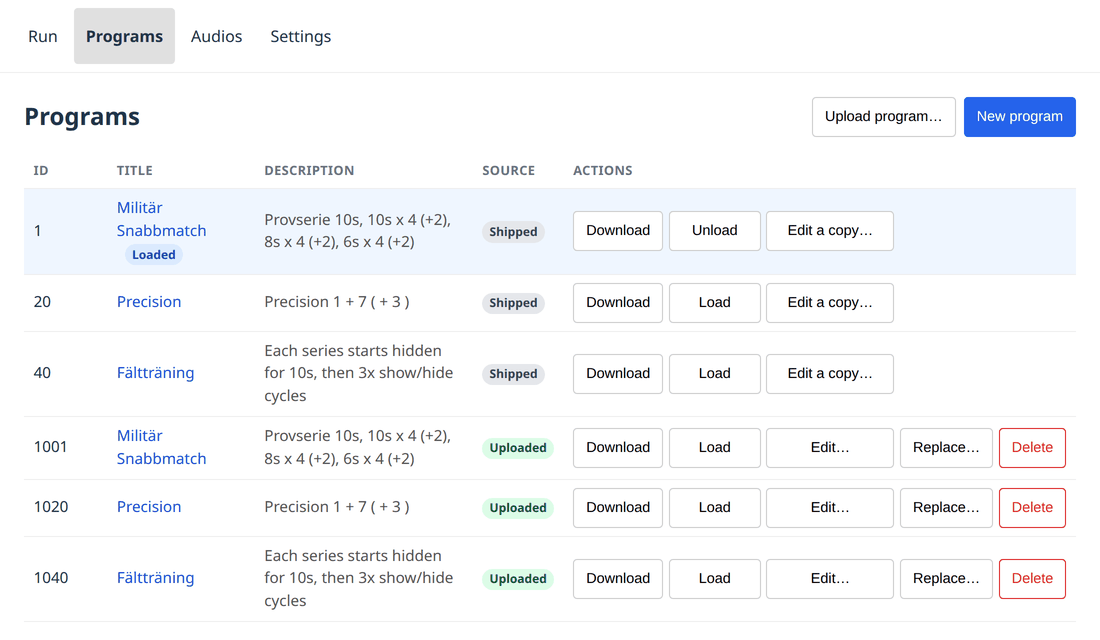
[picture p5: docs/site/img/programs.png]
The Programs page


Each row is one program. **Source** says shipped or uploaded, and the actions
follow from it: an uploaded program can be edited, replaced and deleted, a
shipped one only downloaded or copied.

- **Load** makes it the program the Run page will run. Only one program is
  loaded at a time, and the row says which.
- **Download** saves the program as a `.json` file — the way to get a copy of
  a shipped program to start from.
- **Edit a copy…** on a shipped program opens the editor on a copy, which
  uploads as a new program and leaves the original alone. On an uploaded
  program, **Edit…** changes it in place.
- **Replace…** overwrites an uploaded program from a file.
- **Delete** removes an uploaded program. A shipped one refuses with an
  explanation rather than disappearing from the list.

### Ids

Ids below 1000 are shipped; uploads are numbered from 1000 up. The device
picks the id, not the file — the number inside an uploaded document is
ignored — and it hands back the lowest free one, so deleting 1001 and
uploading again gives 1001 rather than stepping past it.

### Editing

**New program** and the **Edit** actions open the same editor: series and
events as a form, the JSON the device will actually receive on a second tab,
and a read-only timeline preview underneath both. Events carry a duration,
whether they show or hide the targets, and any audio clips to play on entry.

The editor checks the document against what the device will accept before it
sends anything, and says what would be changed or refused rather than letting
the device answer with an error after the fact.

## Audio

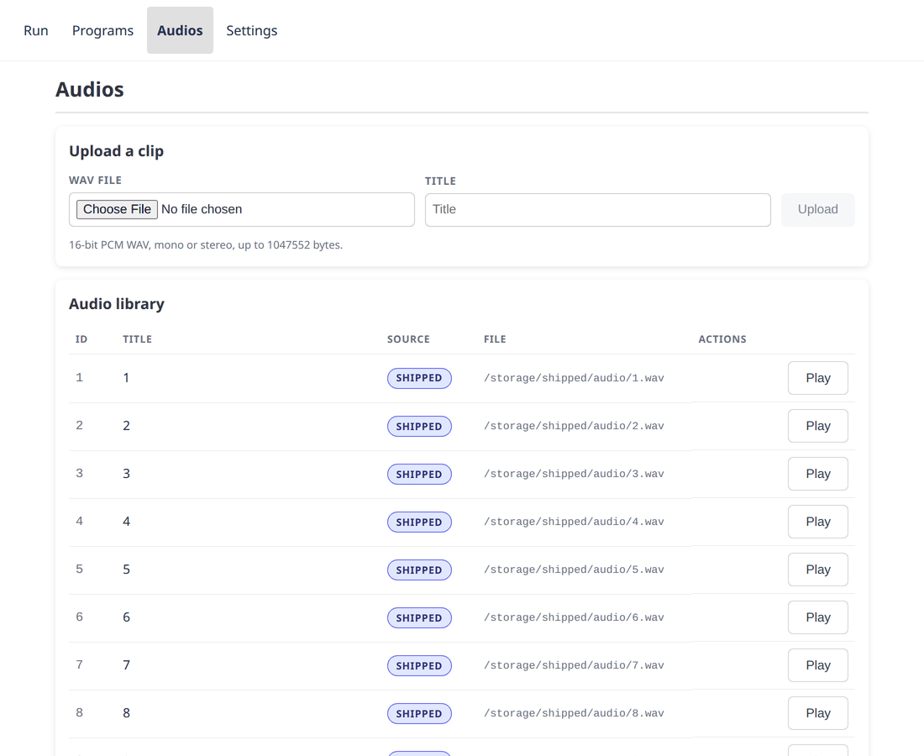
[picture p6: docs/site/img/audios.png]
The Audios page


Clips you upload are **16-bit PCM WAV, mono or stereo**, up to the size the
upload form states. Anything else is refused at upload rather than failing
silently mid-exercise. Nothing is done to them: what you upload is what plays.

The clips that come *with* the device are compressed, which is why they take
about a quarter of the room they used to and why there is more space for yours
than there was. It makes no audible difference at the range — the same file is
what the speaker gets either way — and the originals live in the project's
source, so nothing is lost.

**Play** sends the clip to the device's own amplifier — not to the browser —
so it is a check on the wiring and the speaker, not on the file.

### What cannot be deleted, and why

A spoken command that silently fails in the middle of an exercise is a
range-safety problem, so the device refuses a delete that could cause one. In
the order it checks:

| Reason | Lifts when |
|---|---|
| The clip is shipped with the firmware | never |
| The loaded program plays it | another program is loaded, or the current one is unloaded |
| A run is in progress | the run is paused or finished |
| The device is playing that clip right now | the clip finishes |

Note the second one: pausing is not enough. **Pause** keeps the run's exact
position, so a clip deleted between two halves of a paused run would be
missing when it resumes. Unload the program, or load a different one.

## Getting a program into the shipped set

Uploaded programs live on one device. A program that should be on every
device — and survive a reflash — belongs in the repository, where it ships
with the next firmware.

The route is: **Download** the program from the Programs page, then open a
pull request adding it under `resources/programs/files/` with a filename of
`<id>.json` — an id below 1000, not already taken. The same applies to audio
clips under `resources/audios/`.

The [program editor](https://malmo-skyttegille-pistolsektionen.github.io/rotation_target/editor/) does both halves for you — see
[Writing your own program](writing-a-program.md).

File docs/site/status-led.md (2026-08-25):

# Status LED

The status LED needs a page of its own, because it is the only thing the
device tells you when nobody has a browser open — and at the range that is the
normal case.

There are **two sequences**, not one, and which you are watching is the first
thing to work out: a device that knows a network, and a device that does not.

## A device that knows a network

The ordinary startup, every time the board is powered on at the range:

| LED | Means | What to do |
|---|---|---|
| **Blinking red** | Trying to join the stored network | Wait — it blinks once per join attempt, about every 2.4 s |
| **Yellow** | On the network, not serving yet | Normally invisible (~24 ms). If it *stays* yellow, WiFi is fine and the HTTP server is the fault |
| **Green** | Serving | Normal running state — [go and find it](connecting.md#finding-the-device) |

Blinking red for a few seconds on every boot is expected; joining a network is
not instant. It is only a problem if it does not end.

## A device that does not

A board that has never been configured, or that has been moved somewhere its
stored network does not exist, runs out of attempts and offers a network of its
own instead:

| LED | Means | What to do |
|---|---|---|
| **Blinking red** | Trying, and failing, to join | Wait for it to give up — it will |
| **Blue** | Setup portal on its own access point | [Join it and configure a network](connecting.md#the-setup-portal) |

After the portal saves a network, the device restarts and runs the first
sequence instead: blinking red, then green.

**Solid red** belongs to neither: it means the device gave up *and* did not
raise the portal. That is a fault rather than a state to act on — see
[Troubleshooting](troubleshooting.md).

## White — you are holding the button

**White** is not a state the device gets into on its own. It appears three
seconds into a hold of the **BOOT** button and means the device is counting
towards a [factory reset](connecting.md#moving-the-device-to-a-different-network).

Let go and it goes back to whatever colour it was showing. Keep holding to ten
seconds and it restarts, having forgotten every network it knows.

If you see white and did not mean it, let go — nothing has happened yet.

If the LED goes white **on its own**, without anybody touching the button, the
button is stuck or shorted. The device notices — it refuses to act on a button
it has never seen released, so it will not reset itself — but the button will
not work until the fault is fixed. The serial log says so in as many words.

## Three things worth saying, because none is guessable

- **Blinking versus solid red is the important distinction.** Before
  [#122](https://github.com/Malmo-Skyttegille-Pistolsektionen/rotation_target/issues/122)
  both were solid, so "still coming up" and "never joined" looked identical —
  which is exactly the question you have at the range.
- **Yellow is a fault indicator, not a stage.** It exists to be seen only when
  something is wrong.
- **White is the only colour that answers to you rather than reporting on the
  device.** Every other colour is something to read; white is feedback on
  something you are doing to it right now.

The LED is deliberately dim: the device sits on a range in the dark and a
bright indicator is a distraction downrange. Photographs for these docs should
be taken in low light or it will not read as the colours above.

<!-- TODO: low-light photographs of each LED state, per the note above -->

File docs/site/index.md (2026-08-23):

# Rotation Target

Software for running timed shooting programs on a rotating target system, built
by and for Malmö Skyttegille Pistolsektionen.

An ESP32-S3 board turns the targets face-on and edge-on to a shooting program
and plays the spoken range commands over an amplifier. A React web app — served
by the board itself over WiFi — starts and stops programs, follows the run live,
and manages the stored programs and audio.

The board does not speak any target system's proprietary protocol: it closes
and opens one circuit, and the target system's own electronics do the rest.
It was built against the [Eigenbrod TP2](https://eigenbrod-schiessanlagen.de/en/products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), but
anything driven the same way — a contact closure, level-driven, two positions —
should work.

!!! danger "Safety warning — read before installing or operating"

    **This device moves steel on a live firing range, and it moves it on a
    timer.** A target turns because a program said it was time, not because it
    can see who is in front of it. It has no idea anyone is downrange.

    - **The range's own safety rules and range commands govern the line. This
      software governs nothing.** A program running is not a range that is hot;
      a program stopped is not a range that is safe.
    - **Never go downrange because the web app says the run has finished.**
      Confirm a cease-fire the way your range already requires — verbally, with
      firearms cleared and benched.
    - **A target turning can injure somebody standing next to it.** Keep clear
      of the mechanism whenever the device is powered.

    **Do not rely on this software to protect anyone.** It is a convenience for
    running programs, not a safety device: no interlock, no sensor, and no way
    to know where people are.

    This project is provided as-is with no warranty of any kind. The authors
    accept no responsibility or liability for any injury, damage or loss
    resulting from building, installing, modifying or operating this system.

The targets rest face-on and stay there at boot by design: somebody may be
downrange when a board is powered, and a target that turns on its own can
injure them. That resting state can be changed to suit a target system wired
the other way round, but only over a serial cable — see [Settings](settings.md).

## Where to start

- [Hardware and wiring](hardware.md) — the DB9 connector and what a target
  system has to be to work with the board.
- [Connecting](connecting.md) — join the device's network and open the web app.
- [Running a program](running-a-program.md) — start, follow, and stop a run.
- [Status LED](status-led.md) — what the device is telling you when nobody has
  a browser open.
- [Troubleshooting](troubleshooting.md) — common problems and what to check.

## Program editor

[**Open the program editor**](editor/){ .md-button } — write and edit programs
in a browser with **no device attached**, then download the file or open a pull
request. Also the easiest way to read a shipped program without a board in
front of you.

## Write a program without a device

The **[program editor](https://malmo-skyttegille-pistolsektionen.github.io/rotation_target/editor/)** runs entirely in a browser tab, with no board
attached. Open a program from this repository, edit it, and either download the
file or open a pull request with it. [Writing your own
program](writing-a-program.md) walks through building one from nothing.

## Source

Full technical documentation — hardware wiring, the API contract, and the
firmware and web app internals — lives in the
[repository](https://github.com/Malmo-Skyttegille-Pistolsektionen/rotation_target).

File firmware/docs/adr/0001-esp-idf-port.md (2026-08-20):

# 1. Port the rotation target backend to native ESP-IDF

Date: 2026-08-19

## Status

Accepted

## Context

The rotation target backend runs on an ESP32-S3-DevKitC-1 N16R8 and is
currently MicroPython + Microdot. That stack has served the club well, but the
device is on a live range and a few properties of it have become limits:

- **No OTA and no rollback.** Updating means `mpremote` over USB, per device.
- **Failure is silent.** An unhandled exception drops to a REPL or reboots with
  nothing recorded; there is no core dump and no watchdog.
- **Timing is coarse.** The run loop's accuracy is bounded by the interpreter,
  and audio playback shares the same asyncio loop as the HTTP server.
- **The test suite could not reach the hardware boundary.** Firmware modules
  had to be stubbed wholesale in `conftest.py`, and the executor tests drove
  real `asyncio.sleep`s, which made timing assertions loose.

`AutoLee` — the club's other ESP32 firmware — had already moved from
Arduino/PlatformIO to native ESP-IDF and established a working shape: pure
logic in a component shared by the firmware and host tests, vendored
PsychicHttp for REST + SSE, Unity suites under `host_test/`.

## Decision

Port the backend to native ESP-IDF (C++17, `idf.py`), following AutoLee's
structure:

- Hardware-independent logic in `lib/rt_logic/`, registered as an ESP-IDF
  component and compiled unchanged into the host tests.
- `rt::Executor` takes its clock and side effects by reference, so the run
  state machine is driven deterministically on the host.
- PsychicHttp (vendored, MIT) for REST and `PsychicEventSource` for `/sse/v2`.
- ArduinoJson vendored as the single-header release rather than pulled from the
  component registry, so `host_test/` parses with the same code the firmware
  does without needing the Component Manager.
- The shipped audio and programs come from the `rotation_target_backend_resources`
  repository as a submodule and are flashed as a LittleFS image, rather than
  being copied into this repo as the MicroPython backend did.

The API contract (`docs/api-v2.md`) is unchanged: this is a reimplementation
behind the same wire format, not a redesign.

## Consequences

**Gained:** task and interrupt watchdogs with panic, core dump to flash,
brownout detection, the partition layout and rollback machinery for OTA (the
update *endpoint* is still to come - today the only way to write the second
slot is `idf.py app-flash` over USB), a run loop that wakes on event
and second boundaries within 200 ms, audio on its own task at its own priority,
and a host test suite that exercises the real executor with no sleeps.

**Cost:** C++ instead of Python, a toolchain to install, and a second backend
implementing the same contract — the two can drift. `docs/api-v2.md` is the
shared contract that has to stay true of both, and the deviations section is
where any divergence must be recorded.

**Not carried over:** the `wifi_credentials.py` multi-network list. Credentials
are `sdkconfig` values (`CONFIG_RT_WIFI_SSID`/`_PASSWORD`), still out of git,
but only one network. If the club needs the fallback list back, it should be
NVS-backed and settable over the API rather than compiled in.

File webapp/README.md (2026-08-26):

# Rotation Target Frontend Webapp

This project is a frontend application for controlling rotating targets for Malmö Skyttegille shooting club. The system communicates with an ESP32 backend via REST API and Server-Sent Events (SSE).

## Tech Stack

- **Language:** TypeScript
- **Framework:** React 19
- **Routing:** TanStack Router
- **State/Data:** TanStack Query
- **Build Tool:** Vite
- **Package Manager:** npm
- **Styling:** CSS Modules (CLSX)
- **Linting/Formatting:** ESLint, Prettier

## Features

The web app has the following main features:

1.  **Run Tab:**
    - Load programs (shooting series).
    - Start/stop series.
    - Show timeline and stopwatch for series.
    - Manual target control (Show/Hide).
    - Real-time updates from hardware via SSE.

2.  **Audio Tab:**
    - Upload audio files to hardware.
    - Play audio (for testing).
    - Manage audio library.

3.  **Programs Tab:**
    - List the programs on the device, shipped and uploaded.
    - Load a program, upload one from a file, replace one, delete one.
    - Inspect a program's timeline and download its JSON.
    - Author a program in the editor: series and events, durations, target
      commands and audio clips, with a JSON view and a timeline preview.

4.  **Settings Tab:**
    - Configure backend IP address.
    - The control lock.

5.  **Program editor, off the device (GitHub Pages):** the same `ProgramEditor`
    component as the Programs tab, in a "no device" mode — open a program from
    this repo, another repo, or a local file (or start empty), edit it, then
    download it or send it back as a pull request. See
    [Standalone program editor](#standalone-program-editor-github-pages)
    below.

## Development

### Start dev server

```bash
npm run dev
```

This starts the Vite server at `http://localhost:8080`.
A built-in **Mock Server** simulates the hardware API and SSE streams, so you can develop without physical hardware. It lives in `test/mock-server/`;
`vite-plugins/mock-server-v2.ts` only mounts it on the dev server. Interim —
E2E is moving to the real firmware under QEMU.

### Tests

```bash
npm run test        # once, as CI runs it
npm run test:watch
```

Vitest, with happy-dom for the suites that touch the DOM (opted into per file
with `@vitest-environment happy-dom`). Suites that need an API construct the
mock server with a **fake clock**, so a 28-second series is simulated in
microseconds instead of 28 seconds of wall clock.

### Build for production

```bash
npm run build
```

This generates an optimized build in the `dist/` folder.

### Version

The bundle's version is the release tag, resolved at build time by
`vite.config.ts` from the same `git describe` the firmware's CMake runs and
injected as `__APP_VERSION__` (read it through `src/appVersion.ts`). The webapp
ships inside the firmware image, so the two report identical strings; the
Settings page shows both, and flags a disagreement.

`package.json`'s `"version": "0.0.0"` is a **placeholder**. npm wants the field;
nothing reads it and nothing bumps it. A release is a tag — see
[`docs/RELEASING.md`](../docs/RELEASING.md) and D-29 in the decision log.

### Code style

The project uses strict ESLint and Prettier.

```bash
npm run lint
npm run format
```

### Size budget

CI fails the build if the gzipped total of `dist/**/*.{js,css}` exceeds the
ceiling in `webapp/size-budget` (the same check as
`.github/workflows/webapp-build.yml`). To regenerate it after a deliberate
size change (current total + 5%):

```bash
npm run build
total=0
while IFS= read -r -d '' f; do
  total=$((total + $(gzip -nc "$f" | wc -c)))
done < <(find dist -type f \( -name '*.js' -o -name '*.css' \) -print0)
echo "$total * 1.05" | bc | cut -d. -f1 > size-budget
```

This measures `dist/`, produced by `npm run build` (`vite.config.ts`) only.
The standalone program editor below is a **separate build**
(`vite.editor.config.ts`, output `dist-editor/`) precisely so that adding to
it never grows this number — see the comment on `ProgramEditor`'s
`renderExport` prop for how the device build avoids even importing that code.

### Standalone program editor (GitHub Pages)

```bash
npm run dev:pages-editor          # http://localhost:8080, no mock API mounted
npm run build:pages-editor        # -> dist-editor/, base /rotation_target/editor/
```

`editor.html` / `src/editor-main.tsx` build the same `ProgramEditor` component
the Programs tab uses, in a mode with no device: it opens a program from a
GitHub repo's `resources/programs/files/` (via the contents API, no auth
needed for a public repo), from a local file, or empty; downloads the result;
and can hand it back as a pull request through a prefilled
`github.com/<owner>/<repo>/new/main` URL — no OAuth, no token, nothing to
leak. See [`src/lib/pr-url.ts`](src/lib/pr-url.ts) and
[`src/lib/github-contents.ts`](src/lib/github-contents.ts).

`.github/workflows/pages.yml` builds this alongside the MkDocs docs site
(`#134`) and deploys both as one GitHub Pages artifact, the editor nested
under `/editor/` — GitHub Pages has one deployment target per repo, so two
workflows both calling `deploy-pages` would race each other for it.

## End-to-end tests

The E2E suite (`e2e/`, Playwright) runs against the **real firmware** booted in
QEMU — not the mock server, and not a dev-server proxy. The webapp is built,
its `dist` is baked into the LittleFS image through `RT_WEBAPP_DIR`, that image
is booted, and the browser is pointed at the forwarded guest port. The bundle
under test is the artefact the board actually serves, so the webapp cannot
drift away from the backend without a red build.

```bash
. <esp-idf>/export.sh               # QEMU needs the ESP-IDF toolchain
npm ci
npx playwright install chromium     # `.npmrc` sets ignore-scripts; not automatic
npm run e2e:local                   # build -> boot QEMU -> test -> tear down
```

`e2e/run-local.sh` takes `--skip-build` (reuse the existing `dist` and
`build-qemu`) and `--port N`, and passes anything after `--` to
`playwright test`. It always kills QEMU on the way out, and prints the tail of
the guest serial log when something fails.

`npm run e2e` runs the tests alone, against whatever is already serving on
`RT_E2E_BASE_URL` (default `http://localhost:8080`) — a QEMU instance you
started yourself, or a real board.

Notes for writing tests:

- There is **one device** and its state persists across tests, so the config
  pins `workers: 1` and every spec calls `resetDevice()` in `beforeEach`.
- Deep links are fine to navigate to: the firmware answers a non-API `GET` miss
  with `index.html`, so `/run` reloads as the page it is.
- `backend_issue` is not covered — it needs audio hardware, and QEMU emulates
  no I2S.

CI runs the same thing in `.github/workflows/webapp-e2e.yml`.

## API types

`src/api/generated.d.ts` is generated from the canonical REST contract
(`../contracts/openapi.yaml`) by `openapi-typescript`:

```bash
npm run generate:api
```

The output is committed, and CI re-runs the generator and fails the build on
`git diff` — so a merged contract change that the webapp hasn't caught up
with is a red build, not a silent runtime mismatch. `src/api/types.ts`
re-exports the shapes it actually uses from `components['schemas'][...]` in
the generated file; SSE payload types (`contracts/asyncapi.yaml` is not fed
to the generator) stay hand-written there.

The app does not ship a JSON Schema. `src/lib/program-document.ts` validates
program documents against what the firmware's `parse_program` actually does
(D-18); `test/program-document-schema.test.ts` cross-checks that against
`../contracts/program.schema.json` with ajv, which is why ajv is still a
devDependency.

## UI/UX

Primary audience is tablet and mobile, which requires larger, touch-friendly buttons and controls.

## Project Structure

- `src/`: Source code (React)
  - `routes/`: Application routes (TanStack Router)
  - `components/`: Reusable components
  - `hooks/`: Custom hooks (e.g. useSSE)
  - `api/`: API clients and types
  - `lib/`: Pure logic shared with the mock server (e.g. run-position, which
    mirrors `firmware/lib/rt_logic/run_position.h`)
- `vite-plugins/`: Dev-server plugins (the mock server adapter)
- `test/`: Unit tests, fixtures and the mock server implementation

## Security

The project is configured to minimize supply-chain attack risk:

- Dependencies are locked via `package-lock.json` (`npm ci` in CI).
- Install scripts are disabled via `.npmrc` (`ignore-scripts=true`); no
  package's `postinstall`/`preinstall` runs on `npm install` or `npm ci`.
- Yarn's `npmMinimalAgeGate` (a per-install minimum package age) has no npm
  equivalent; the managed path is instead covered by the org's shared
  Renovate config, `minimumReleaseAge` (3 days for minor/patch updates, 7
  days for major).

## Contact

Project maintained by MSG.

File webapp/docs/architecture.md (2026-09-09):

# System Architecture

## Overview

Rotation Target is a system for controlling rotation targets at a shooting club. The system consists of:

1. **ESP32 Backend** - Hardware controller with REST API + SSE
2. **Frontend SPA** - React app for tablets/mobile devices
3. **Mock Server** - Development server simulating ESP32 behavior

```
┌─────────────────────────────────────────────────────────────────┐
│                        ESP32 BACKEND                            │
│  ┌─────────────────────────────────────────────────────────┐    │
│  │                    STATE (source of truth)              │    │
│  │  - loadedProgram (id, series, events)                   │    │
│  │  - programState (running, seriesIdx, eventIdx, ticker)  │    │
│  │  - targetBanks (per bank: shown/hidden)                 │    │
│  └─────────────────────────────────────────────────────────┘    │
│                            │                                    │
│         ┌──────────────────┼──────────────────┐                 │
│         ▼                  ▼                  ▼                 │
│  ┌────────────┐    ┌────────────┐     ┌────────────┐            │
│  │  REST API  │    │  REST API  │     │    SSE     │            │
│  │  /api/v2/* │    │  /api/v2/* │     │  /sse/v2   │            │
│  │  (POST)    │    │  (GET)     │     │  (stream)  │            │
│  │ mutations  │    │ large data │     │ live state │            │
│  └────────────┘    └────────────┘     └────────────┘            │
└─────────────────────────────────────────────────────────────────┘
        ▲                  │                   │
        │ POST             │ GET               │ stateUpdate event
        │                  │ programs,         │
        │                  │ program/{id}      ▼
┌─────────────────────────────────────────────────────────────────┐
│                      FRONTEND (React SPA)                       │
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

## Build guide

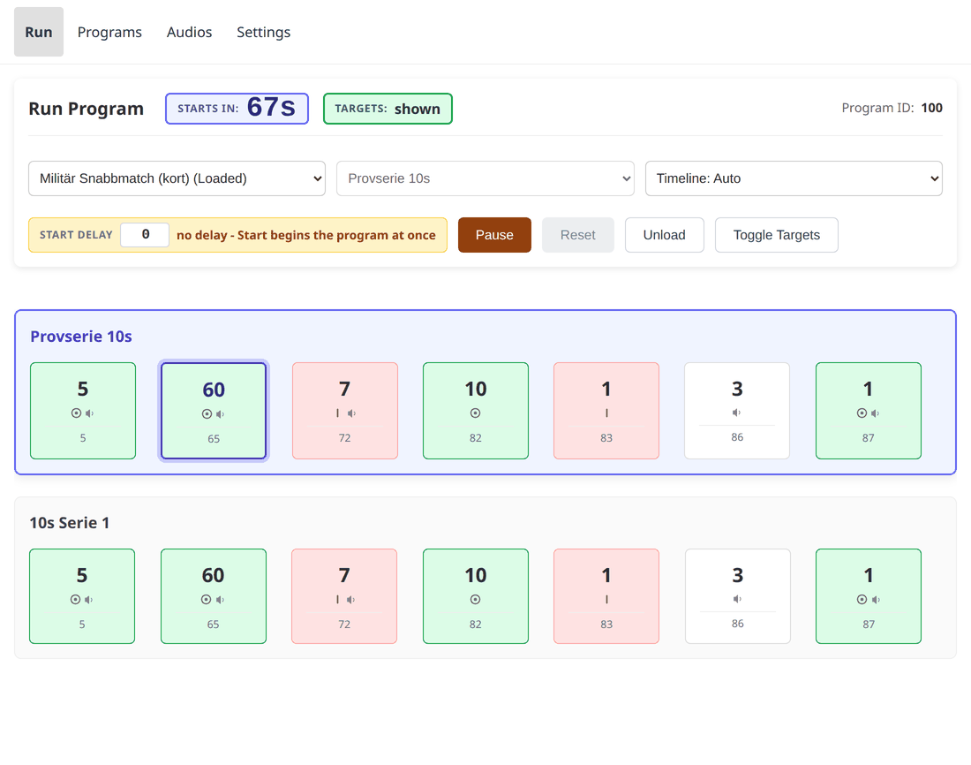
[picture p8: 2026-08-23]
docs/site/img/tutorial-countdown.png

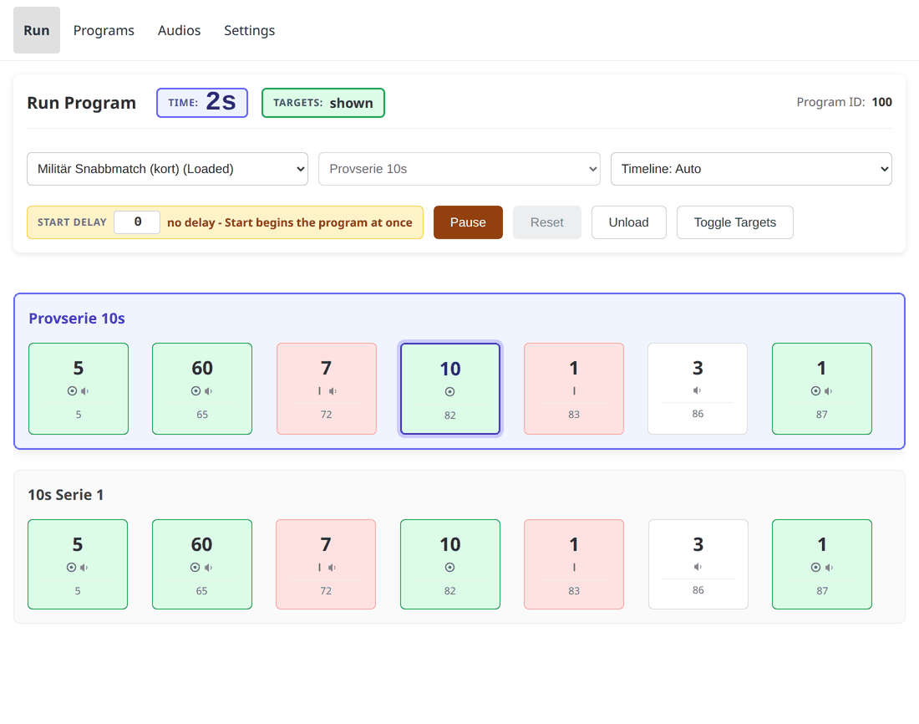
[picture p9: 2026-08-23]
docs/site/img/tutorial-shooting.png

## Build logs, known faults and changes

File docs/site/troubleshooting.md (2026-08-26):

# Troubleshooting

Start with the [status LED](status-led.md) — it is the only feedback the
device gives when no browser is open, and it distinguishes "still connecting"
from "never connected" at a glance. Most of what follows starts by reading it.

## Device not found

| LED | Meaning | What to do |
|---|---|---|
| Blinking red | Still trying to join a network | Wait — nothing to fix yet |
| Solid red | Gave up joining; the setup portal should be up | See [Connecting](connecting.md#the-setup-portal) |
| Blue | On the setup portal's own network | It has no range network yet — go through setup |
| Yellow, and staying that way | On the network, but the web server has not come up | The network side is fine; this is a device fault, not a connection one |
| Green | Serving | The device is reachable — if the browser still cannot reach it, see below |

If the LED is green but `http://rotation-target.local` will not load, the
network is not resolving the mDNS name for you — try the device's IP address
directly instead (see [Connecting](connecting.md#finding-the-device)). Confirm
the browser is actually on the same network as the device, not still on
mobile data or a previous WiFi.

## Targets not moving

- Try **Toggle Targets** on the Run page. If that does not move the targets
  either, the problem is not the loaded program — check power to the target
  system and the DB9 connection (see [Hardware](hardware.md)).
- If Toggle Targets works but a program does not move them, check the
  program's timeline: an event with no show/hide command is a timed pause by
  design, not a fault.
- If the targets move, but the wrong way — showing when they should hide, or
  the reverse — that is a build-time wiring setting, not something fixable
  from the web app. Report it rather than rewiring anything.

## No audio

- Confirm the amplifier is powered and connected — the device has no way to
  detect that on its own.
- Some devices are built with audio hardware disabled entirely; a target that
  only turns, with no sound, is a supported configuration on those. If that is
  the case for this device, there is nothing to fix.
- A clip that fails to play (missing, or not a playable file) is reported by
  the device as a **backend issue** banner — currently surfaced on the Audios
  page, not the Run page, so check there if a run went quiet. <!-- TODO: confirm whether this should also surface on the Run page -->
- The run itself is unaffected by a clip failing to play: it carries on
  silently through that event rather than stopping.

## "Stop" says the program is not running (400)

`POST /programs/stop` — the Pause action — answers `400` when nothing is
running. This is expected, not a fault, and shows up in one case an operator
will actually hit: **pressing Pause after a series has already finished on its
own** — a series that runs to the end stops itself, so there is nothing left
to pause. If another series follows, the device has already selected it and
is waiting at its first event; press Start to run it. If that was the last
series, the program has finished — Start would replay it from the beginning,
or Unload to pick something else.

## Sending a fault report

When the device has misbehaved and nobody at the range can say why, send a
**troubleshooting bundle** rather than a description of the symptoms. It is one
zip file holding what the device knows about itself — its version, how much
memory and storage it has left, why it last restarted, and what it complained
about at startup — plus, if it crashed, the crash dump itself.

The crash dump is the part that matters, and the part that used to need a cable
and a laptop with developer tools on it. It also has to be read against the
exact firmware that produced it, which stops being the firmware on the board as
soon as somebody updates it — so the bundle carries that identity alongside the
dump.

**To download one:**

1. Press the device's **BOOT** button — the small button next to the USB
   sockets, marked `BOOT` or `FLASH` — **three times within ten seconds.**
2. Open the **Expert mode** tab that appears in the web app, and scroll to
   **Troubleshooting** at the bottom.
3. Press **Download troubleshooting bundle** and attach the file to your
   message.

The tab is only there for five minutes after those three presses, and it does
not appear at all while a program is running. If it is missing, press the button
three times again. [Expert mode](expert-mode.md) covers what else is on it.

!!! warning "Who you can send it to"

    A crash dump is a copy of what was in the device's memory at the moment it
    failed, and that can include **the WiFi password**. That is why downloading
    one needs somebody standing at the board pressing its button, and it is why
    the file should go to somebody you would tell the password to.

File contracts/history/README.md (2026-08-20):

# Historical contracts — API v1

These two files describe **API v1**: the MicroPython backend
(`rotation_target_backend_esp32_micropython`) and the app-era clients that
spoke to it. They are kept as a record of what the system used to promise, and
for the occasional archaeology question — "did v1 have this endpoint, and what
did it answer?" Nothing in this repository implements them.

| File | Describes |
|---|---|
| `openapi.yaml` | REST under `/api/v1` |
| `asyncapi.yaml` | SSE at `/sse/v1`, with the discrete `program_added` / `program_updated` / … lifecycle events |

**They are not maintained.** They were already stale against v1 before being
moved here, and nothing checks them. The canonical contracts are one directory
up; see [`../README.md`](../README.md).

## What v2 changed

- `/api/v1` → `/api/v2`, `/sse/v1` → `/sse/v2`.
- SSE went from discrete lifecycle events to a single `stateUpdate` carrying
  the full run state, plus a `heartbeat`. `GET /status` went away with them:
  the state on connect replaces it.
- `POST /programs/{id}/update` does not exist in v2. There is no update path
  at all — posting a program always creates a new one.
- `backend_issue` (v1's error event) has no v2 equivalent yet.
- Admin mode gained `login` and `logout` alongside `enable`/`disable`, and
  bearer-token authentication alongside the cookie.
- `GET /diagnostics/info` is new in v2.

## The one edit made on the way in

The three `$ref`s in `openapi.yaml` pointed at `./program.schema.json`, which
now lives at `../program.schema.json` — the program document schema is still
current, so it was promoted rather than copied. The references were repointed
so the file still resolves; nothing else was touched.

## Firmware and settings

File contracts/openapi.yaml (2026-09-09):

# yaml-language-server: $schema=https://spec.openapis.org/oas/3.1/schema/2022-10-07
---
openapi: 3.1.0

info:
  title: Rotation target REST API v2
  version: 1.0.0
  license:
    name: MIT
    identifier: MIT
  description: |
    The REST API the rotation target firmware serves under `/api/v2`, together
    with the SSE stream at `/sse/v2` (specified separately in
    `contracts/asyncapi.yaml`).

    This document is **canonical** and is written from the implementation
    (`firmware/main/net/web_server.cpp` and `firmware/lib/rt_logic/`), not the
    other way round. Where prose documentation and the firmware disagree, the
    firmware wins and this file follows it. See `contracts/README.md`.

    ## State model

    There is no `GET /status`. Run state is published only over `/sse/v2`: a
    client connects, immediately receives a full `stateUpdate`, and receives
    another after every mutation. The mutating endpoints here answer with a
    short confirmation message, not with state.

    ## Errors

    Every failure is an **RFC 9457 problem detail** served as
    `application/problem+json` (D-19):

    ```json
    {
      "type": "/problems/program_readonly",
      "title": "Program is read-only",
      "status": 409,
      "detail": "Program is read-only and cannot be deleted"
    }
    ```

    `type` is the discriminator — a **stable relative URI that is never
    dereferenced**, and the only member a client should branch on. `title` is
    short and identical for every occurrence of a type; `detail` describes the
    one occurrence and is the string to show a user. `instance` is omitted:
    it identifies a single occurrence and the device has no request ids.

    One status per `type`, always — so the `type` lists under each operation
    below say exactly what a given status code can mean there.

    The slug vocabulary is **shared with the SSE `backend_issue` codes** in
    `contracts/asyncapi.yaml`: a program that will not parse is
    `/problems/program_invalid` over REST and `program_invalid` over SSE,
    because it is the same failure. The full list is the `enum` on
    `Problem.type`.

    A client must tolerate a `type` it does not recognise — fall back to
    `status` and show `detail`. New types are additive.

    ## Authentication

    The control lock is off after every boot and lives in RAM only. While it is
    off,
    **every endpoint is unauthenticated**, including the ones marked as
    requiring a session below. A client turns protection on with
    `POST /api/v2/control-lock/enable`, choosing the password in that call.

    While the lock is on, the protected endpoints accept either credential:

    - `Authorization: Bearer <token>`
    - `Cookie: control_lock=<token>`

    The header is checked first; the cookie is the fallback. Tokens are 16
    random bytes, hex-encoded, valid for 12 hours from issue, and at most 8
    are held at once (oldest evicted first). `enable` and `login` return the
    token in the body *and* set it as
    `Set-Cookie: control_lock=<token>; Path=/; SameSite=Lax` — deliberately not
    `HttpOnly`, because the webapp reads it back. `SameSite=Lax` means the
    cookie only rides along when the webapp is served from the device itself;
    a webapp on another origin authenticates with the bearer token.

    Because of the "off means open" rule, each protected operation lists an
    empty security requirement alongside the two credentials: with the lock
    disabled, a call with no credentials succeeds.

    ## CORS

    The firmware answers credentialed cross-origin requests against an
    allowlist rather than with `*` (a browser refuses a wildcard on a
    credentialed request). An `Origin` header is echoed back in
    `Access-Control-Allow-Origin`, with `Access-Control-Allow-Credentials:
    true`, `Access-Control-Allow-Methods: GET, POST, PUT, DELETE, OPTIONS`,
    `Access-Control-Allow-Headers: Authorization, Content-Type`,
    `Access-Control-Max-Age: 600` and `Vary: Origin`, only when it is one of:

    - `http(s)://<CONFIG_RT_HOSTNAME>.local` (default `rotation-target.local`)
    - `http(s)://<the device's current IP>`
    - `CONFIG_RT_DEV_ORIGIN`, when that Kconfig value is non-empty

    Any other origin gets no CORS headers at all, so the browser blocks the
    response.

    ## Routes that exist but are not modelled as paths here

    Both are catch-alls that would have to be attached to every path to be
    modelled honestly, so they are recorded here instead:

    - `OPTIONS /*` — a single catch-all preflight handler answering `204` with
      no body (with the CORS headers above when the origin is allowed).
      Registered because nothing else answers `OPTIONS`, and a preflight that
      404s fails the real request behind it.
    - `GET /*` — the built webapp, served from the LittleFS path
      `/storage/webapp/` with `index.html` as the default file. Registered
      last so it can never shadow an API route.
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

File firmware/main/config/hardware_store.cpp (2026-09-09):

#include "hardware_store.h"

#include <cstring>

#include "config.h"
#include "esp_log.h"
#include "hardware_overlay.h"
#include "nvs.h"
#include "sdkconfig.h"

namespace hardware_store {
namespace {

const char *TAG = "hw_store";

// The same namespace `wifi_store` writes to, so one `nvs` partition holds all
// of the device's provisioning rather than two.
constexpr const char *kNamespace = "rotation";

// The key names, `BankKey` and the overlay's decision table all live in
// rt_logic (`hardware_overlay.h`), where host tests reach them. This file is
// the NVS half: opening the namespace, the typed reads, and the writes.
using rt::BankKey;
namespace hw_key = rt::hw_key;

rt::HardwareConfig s_current;
bool s_overridden = false;

bool read_str(nvs_handle_t handle, const char *key, std::string &out) {
  size_t len = 0;
  if (nvs_get_str(handle, key, nullptr, &len) != ESP_OK || len == 0) return false;

  out.resize(len);
  if (nvs_get_str(handle, key, &out[0], &len) != ESP_OK) return false;
  // nvs_get_str counts the NUL; std::string tracks its own length.
  out.resize(len > 0 ? len - 1 : 0);
  return true;
}

// A key that was not there is already in the state the caller wanted.
bool erase_if_present(nvs_handle_t handle, const char *key) {
  const esp_err_t err = nvs_erase_key(handle, key);
  return err == ESP_OK || err == ESP_ERR_NVS_NOT_FOUND;
}

// One NVS getter per stored type, matching what `save()` writes.
class NvsReader : public rt::ConfigReader {
 public:
  explicit NvsReader(nvs_handle_t handle) : handle_(handle) {}

  bool read_i32(const char *key, int32_t &out) override {
    int32_t value = 0;
    if (nvs_get_i32(handle_, key, &value) != ESP_OK) return false;
    out = value;
    return true;
  }

  bool read_bool(const char *key, bool &out) override {
    int8_t value = 0;
    if (nvs_get_i8(handle_, key, &value) != ESP_OK) return false;
    out = value != 0;
    return true;
  }

  bool read_str(const char *key, std::string &out) override {
    return hardware_store::read_str(handle_, key, out);
  }

 private:
  nvs_handle_t handle_;
};

}  // namespace

rt::Peripherals peripherals() {
  rt::Peripherals present;
#if CONFIG_RT_AUDIO_ENABLED
  present.audio = true;
#else
  present.audio = false;
#endif
#if CONFIG_RT_RGB_LED_ENABLED
  present.led = true;
#else
  present.led = false;
#endif
  return present;
}

rt::HardwareConfig defaults() {
  rt::HardwareConfig config;
  // One bank, from the Kconfig the single target used to come from. A second
  // bank is something a device is told about, never something it ships with.
  config.banks.assign(1, rt::TargetBank{});
  config.banks[0].gpio = CONFIG_RT_TARGET_GPIO;
#if CONFIG_RT_TARGET_ACTIVE_LOW
  config.banks[0].active_low = true;
#else
  config.banks[0].active_low = false;
#endif
  config.hostname = CONFIG_RT_HOSTNAME;
#ifdef CONFIG_RT_TARGETS_HIDE_AT_BOOT
  config.targets_shown_at_boot = false;
#else
  config.targets_shown_at_boot = true;
#endif

  // Carried whether or not the peripheral is compiled in, so a value set on a
  // build that had it survives one that does not.
#if CONFIG_RT_RGB_LED_ENABLED
  config.led_gpio = CONFIG_RT_RGB_LED_GPIO;
#endif
#if CONFIG_RT_AUDIO_ENABLED
  config.i2s_port = CONFIG_RT_I2S_PORT;
  config.i2s_bck_gpio = CONFIG_RT_I2S_BCK_GPIO;
  config.i2s_ws_gpio = CONFIG_RT_I2S_WS_GPIO;
  config.i2s_dout_gpio = CONFIG_RT_I2S_DOUT_GPIO;
#endif
  config.http_port = CONFIG_RT_HTTP_PORT;
  // The QEMU profile builds without WiFi, so the symbol does not exist there.
  // The struct's own default stands in - nothing reads it on a build with no
  // radio to retry on.
#ifdef CONFIG_RT_WIFI_MAX_RETRIES
  config.wifi_max_retries = CONFIG_RT_WIFI_MAX_RETRIES;
#endif

  // No compiled default: a device that has never been named has no name to
  // show, and inventing one would put the same string on every device.
  config.display_name = "";
  return config;
}

namespace {

// The compiled defaults with whatever NVS currently holds laid over them.
// Returns whether anything was overlaid. The decision table itself is
// rt::overlay_config, so host tests can reach it without an NVS.
bool overlay_from_nvs(rt::HardwareConfig &out) {
  nvs_handle_t handle;
  if (nvs_open(kNamespace, NVS_READONLY, &handle) != ESP_OK) return false;

  NvsReader reader(handle);
  const bool found = rt::overlay_config(reader, out);

  nvs_close(handle);
  return found;
}

}  // namespace

namespace {

bool same_as(const rt::HardwareConfig &a, const rt::HardwareConfig &b) {
  return a.banks == b.banks && a.hostname == b.hostname && a.display_name == b.display_name &&
         a.targets_shown_at_boot == b.targets_shown_at_boot && a.led_gpio == b.led_gpio &&
         a.i2s_port == b.i2s_port && a.i2s_bck_gpio == b.i2s_bck_gpio &&
         a.i2s_ws_gpio == b.i2s_ws_gpio && a.i2s_dout_gpio == b.i2s_dout_gpio;
}

}  // namespace

rt::HardwareConfig saved() {
  // Re-read rather than served from the cache: between a write and the restart
  // that adopts it, this is the only thing that knows what the device has been
  // told. That gap is exactly what `restartRequired` reports.
  rt::HardwareConfig out = defaults();
  overlay_from_nvs(out);
  // A stored value this build refuses is reported as the default it will
  // actually boot on, matching init()'s fallback - so the API never claims the
  // device is about to use something it would reject.
  if (rt::validate(out, peripherals()) != rt::ConfigRefusal::kNone) return defaults();
  return out;
}

void init() {
  s_current = defaults();
  s_overridden = overlay_from_nvs(s_current);

  // A configuration written by an older firmware, or corrupted in place, must
  // not brick the device: fall back rather than driving a pin this build does
  // not consider safe.
  rt::ValidationDetail detail;
  const rt::ConfigRefusal refusal = rt::validate(s_current, peripherals(), &detail);
  if (refusal != rt::ConfigRefusal::kNone) {
    ESP_LOGE(TAG, "Stored configuration refused (%s); using compiled defaults",
             rt::refusal_message(refusal, detail).c_str());
    s_current = defaults();
    s_overridden = false;
    return;
  }

  if (s_overridden) {
    ESP_LOGI(TAG,
             "Hardware configuration from NVS: %u bank(s), bank A gpio=%d active_low=%d, "
             "hostname=%s",
             static_cast<unsigned>(s_current.banks.size()),
             static_cast<int>(s_current.banks[0].gpio), s_current.banks[0].active_low ? 1 : 0,
             s_current.hostname.c_str());
  }
}

const rt::HardwareConfig &current() {
  return s_current;
}
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

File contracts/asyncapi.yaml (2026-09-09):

# yaml-language-server: $schema=https://raw.githubusercontent.com/asyncapi/spec-json-schemas/refs/heads/master/schemas/3.1.0.json
---
asyncapi: 3.1.0

info:
  title: Rotation target SSE v2
  version: 1.0.0
  license:
    name: MIT
  description: |
    The Server-Sent Events stream the rotation target firmware serves at
    `/sse/v2`, alongside the REST API specified in `contracts/openapi.yaml`.

    This document is **canonical** and is written from the implementation
    (`firmware/main/net/sse_hub.cpp` and
    `firmware/lib/rt_logic/program_state.h`). See `contracts/README.md`.

    ## Why the stream exists

    There is no `GET /status` in API v2. `stateUpdate` is the only channel run
    state is published on, and it is the reason no status endpoint is needed:
    a client connects, is sent the full current state immediately, and is sent
    it again after every change.

    `backend_issue` covers the other direction: a failure the device noticed
    on its own, which no REST response can carry because no client asked for
    it. A clip that will not play and a program file that will not parse are
    both invisible to a client otherwise — the run simply carries on, quietly
    wrong.

    `libraryChanged` covers the third: the stored programs and audio clips are
    fetched over REST, not published here, so a client that did not make the
    change had no way to learn of it. On a range with a laptop and a phone
    both open, the second one showed a stale list until somebody reloaded it.

    ## Connection behaviour

    - `GET /sse/v2` answers `200` with `Content-Type: text/event-stream`,
      `Cache-Control: no-cache` and `Connection: keep-alive`. The CORS
      headers described in the OpenAPI document apply here too.
    - On connect, before anything else, the server sends one `stateUpdate`
      carrying the full current state, with `retry: 500` — so a browser
      `EventSource` reconnects half a second after a drop. Later frames carry
      no `retry`.
    - Every frame carries an `id:` field: the device's uptime in
      milliseconds. It is a monotonic ordering hint, not a resumption cursor
      — a client's `Last-Event-ID` is read on reconnect but nothing is
      replayed from it, and the fresh `stateUpdate` on connect makes replay
      unnecessary.
    - A `heartbeat` follows every 10 seconds
      (`kSseHeartbeatSeconds`, `firmware/main/config.h`), whether or not
      anything changed.
    - `libraryChanged` is emitted when a REST call changes what
      `GET /api/v2/programs` or `GET /api/v2/audios` would return, and is
      **fire-and-forget** on the same terms as `backend_issue` below: nothing
      is buffered for a client that connects later and nothing is replayed on
      reconnect. A client that was not listening does not need it — it fetches
      both lists on connect anyway.
    - `backend_issue` is emitted only when something fails, and is
      **fire-and-forget**: it is delivered to whoever is connected at that
      instant and to nobody else. Nothing is buffered for a client that
      connects later, nothing is replayed on reconnect, and there is no
      endpoint that lists past issues. A client that was not listening did
      not hear it — the device log is the record, the event is the
      notification. Issues raised during boot, before the HTTP server
      exists, reach no client on this stream at all; those are kept instead
      and served by `GET /api/v2/diagnostics/info` as `startupIssues`, the
      one exception to "no endpoint lists past issues".
    - The stream is one-way and public: no credential is required, and
      nothing a client sends on it is read.

    ## Delivery guarantees

    State is serialized *and* queued under a single lock, and the frames are
    then written from the HTTP task, so the order clients see is the order the
    state actually took. If the HTTP work queue is full — the task wedged or
    badly behind — a frame is **dropped** rather than blocking the run loop,
    so a client may miss an intermediate state. It will not miss the final
    one for long: the next mutation or the next connect republishes.

    Dead clients are reaped on the heartbeat cadence: a peer that closed
    cleanly is detected by a non-destructive peek, and TCP keepalive
    (30 s idle, 10 s interval, 3 probes) catches a peer that vanished without
    a FIN.

    ## Sockets

    The server keeps at most 12 sockets open, and every connected client holds
    one of them for this stream on top of its REST traffic.

servers:
  device:
    host: rotation-target.local
    protocol: http
    description: >-
      The device on the range network, by mDNS name. Hostname from
      `CONFIG_RT_HOSTNAME`, port from `CONFIG_RT_HTTP_PORT` (default 80).
  qemu:
    host: localhost:8080
    protocol: http
    description: The firmware under QEMU, through the host-forwarded port.

defaultContentType: application/json
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

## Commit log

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2026-08-19 feat: sanitizers, host-testable parsers, NVS wifi and diagnostics
    Acts on the five prioritised improvements from the review passes. Four land
    here; the fifth is a schema fix in the resources repository and is a separate
    PR there.
    **Sanitizers in CI**
    `-DRT_SANITIZE=ON` builds the host suites with ASan + UBSan, and CI runs it as
    a job alongside the plain build — the sanitizers force `-O1` and change
    codegen, so a clean run of one is not evidence about the other. UBSan is what
    catches signed overflow in the duration and id arithmetic, which `-Wall`
    cannot see.
    The vendored ArduinoJson raises `-Wmaybe-uninitialized` at `-O1`; marking the
    include SYSTEM does not suppress it, because it is r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
    [audio.cpp]
2026-08-19 fix: address the review findings
    Fixes the defects the four review passes found, beyond the parser and WiFi
    work already done.
    **SSE: one sender, on the httpd task**
    Sends now go through httpd_queue_work, so PsychicEventSource::send() always
    runs on the httpd task. That fixes three findings at once:
    - The fan-out no longer runs on the run loop. sendEvent retries
    httpd_socket_send forever on HTTPD_SOCK_ERR_TIMEOUT, so one client that had
    stopped reading stalled the run loop in 5-second multiples - freezing the
    targets mid-program while the state said "running".
    - PsychicHandler::_clients has no lock, and esp_http_server mutates it on the
    httpd task when clients connect and disconne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
    [audio.cpp]
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2026-08-19 feat: make board hardware configurable via Kconfig
    The firmware hardcoded the prototype's pins in main/config.h, so a second board
    meant editing source. Every hardware choice is now a menuconfig option under
    "Rotation target backend -> Hardware", and a different board is a different
    sdkconfig.
    - RT_TARGET_GPIO and **RT_TARGET_ACTIVE_LOW**. Polarity matters as much as the
    pin number: a board that buffers or inverts the drive, or switches a relay
    directly, needs the opposite sense, and getting it wrong means the boot-time
    "hide" in targets::init() presents the targets instead.
    - RT_RGB_LED_ENABLED + GPIO. A bare ESP32-S3-WROOM has no WS2812; that LED is a
    DevKitC-1 feature. Disabled,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
    [audio.cpp]
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2026-08-20 feat(contracts): canonical v2 REST and SSE contracts (#18)
    * refactor(contracts): move the API specs out of resources/
    Verbatim move, no content change: the specs were data in a resources tree
    that is otherwise programs and audio, and the webapp and firmware each kept
    their own drifting copy of the API description because there was no obvious
    place for the real one.
    contracts/ is that place. The next commit makes it canonical.
    * feat(contracts): canonical v2 REST and SSE contracts
    contracts/ becomes the canonical API contract, written from the firmware
    rather than from the older documents: contracts/openapi.yaml (OpenAPI 3.1)
    cover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
    [asyncapi.yaml, openapi.yaml]
2026-08-20 feat(firmware): PUT /api/v2/programs/{id} to update a program (#21)
    * feat(rt_logic): report whether a program document declares an id
    parse_program() takes an optional `id_present` out-parameter. A document
    without an `id` parses to 0, and 0 is itself a legal id, so the distinction
    cannot be recovered from the parsed model afterwards - PUT /programs/{id}
    needs it to tell "no id offered" from "id 0 offered" and refuse the latter
    when it disagrees with the path.
    Present means the key exists and is not JSON null, not that it is usable: a
    wrong-typed id reads as 0 but still counts as declared, so it is refused
    rather than quietly renumbered.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
    [openapi.yaml]
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2026-08-20 feat(firmware): backend_issue SSE event for device-side failures (#23)
    * feat(rt_logic): serialize the backend_issue SSE payload
    The values in it are filesystem paths and uploaded filenames, so the
    escaping is the load-bearing part: a raw newline in a path would not just
    break the JSON, it would terminate the SSE data: line and split the frame.
    Host-tested against hand-written expectations and, independently, by
    parsing the output back with ArduinoJson.
    * feat(firmware): backend_issue SSE event for device-side failures
    v2's SSE collapsed to stateUpdate + heartbeat, leaving the device no way
    to report a failure nothing asked for. Two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
    [asyncapi.yaml, audio.cpp, openapi.yaml]
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2026-08-20 feat!: replace tickerSeconds with tickerMs in the stateUpdate payload (#47)
    D-16. `programState.tickerMs` carries milliseconds elapsed in the current
    series and `tickerSeconds` is removed rather than kept beside it: two fields
    for one quantity is two sources of truth that can disagree, and whole seconds
    are a client-side derivation, `Math.floor(tickerMs / 1000)`.
    The webapp's playhead is positioned from this value. Whole seconds put it up
    to a second behind the targets - on Fältträning, whose events are three
    seconds long, that is nearly a whole event. `Executor::tick` already computed
    the exact elapsed millisecond and threw the sub-second part away.
    **Precision, not cadence.** The compa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
    [asyncapi.yaml, openapi.yaml]
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2026-08-20 feat(firmware): refuse to delete audio a run still needs (#79)
    `DELETE /api/v2/audios/{id}/delete` only refused a clip the audio task was
    reading at that instant, so a clip could be deleted mid-run between events, or
    while the loaded program plays it - and the program then reached a missing
    clip. On a range that is a spoken command (cease fire) failing silently during
    an exercise.
    Two rules on top of the is-playing guard, both `409`, existence checked first
    so a bogus id is never reported as a conflict:
    1. the loaded program plays the clip - refused whether or not a run is in
    progress, because `stop` is a pause and a resumed run would hit the same
    hole;
    2. a run is in progres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
    [openapi.yaml]
2026-08-21 feat(webapp): port the Programs tab to React (#72)
    * feat(webapp): port the Programs tab to React
    Adds `/programs`: the list of what the device holds, and the four things a
    club member does with it — load, upload, replace, delete — plus the full
    document and its timeline behind a row.
    Scope is the port of `src_legacy/ui/views/programs_tab.js`. The WYSIWYG
    editor next to it (`program_editor.js`, 2688 lines) is deliberately not in
    this PR; it stays reachable under Legacy App until it is ported on its own.
    Notable choices, both away from the legacy implementation:
    - Replace and upload go through the contract's own verbs — `PUT /programs/{id}`
    (D-15) and `POST /programs`. The endpoin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
    [openapi.yaml]
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2026-08-21 feat(firmware): refuse an unrecognised Event.command (#80)
    * feat(firmware): refuse an unrecognised Event.command
    `command` stays optional, but the firmware now rejects a program whose event
    carries a value it does not act on: absent, JSON `null` and "" mean "leave the
    targets where they are", "show" and "hide" are the vocabulary, and anything
    else fails the whole program the way malformed JSON does. `POST /programs` and
    `PUT /programs/{id}` answer 400 "Invalid program".
    Both clients already refused anything but show/hide; only the device was lax,
    so a typo like "shwo" uploaded cleanly and surfaced mid-exercise as a target
    that simply never turned. `null` and "" are accepted because they a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
    [openapi.yaml]
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2026-08-21 feat(firmware): add POST /api/v2/programs/unload (#88)
    D-15 refuses `PUT /programs/{id}` while the program is loaded, and #79's
    audio guard refuses a clip the loaded program plays -- both telling the
    client to "unload", a verb v2 did not have. The only ways to clear
    `loadedProgramId` were loading some other program or deleting the loaded
    one, so the honest instruction was "load something else first": a
    workaround standing in for a missing operation.
    `POST /api/v2/programs/unload` is admin-gated like every other mutation.
    It clears the selection and publishes a `stateUpdate` with
    `loadedProgramId: null`; the targets stay where the run left them.
    A run in progress is `409` (`A program is run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
    [openapi.yaml]
2026-08-21 fix(firmware): answer 409, not 404, for a delete refused as read-only (#89)
    `DELETE /programs/{id}/delete` gave a shipped program the same `404` as a
    program that does not exist, so a client could not tell "refused because
    it is shipped" from "gone" -- while `PUT` on that same program already
    answers `409`. The two write paths disagreed with each other, and the
    ported Programs tab had to sidestep it by hiding Delete on shipped rows.
    `DELETE /audios/{id}/delete` had the identical asymmetry (`clip->readonly`
    -> `404`), next to the three run-safety `409`s #79 added, so it is fixed
    with it: same issue class, same fix, and leaving one half would trade one
    inconsistency for another. On that path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
    [openapi.yaml]
2026-08-21 feat(firmware): surface boot-time issues on diagnostics/info (#99)
    * feat(firmware): surface boot-time backend_issues on diagnostics/info
    `program_invalid` was a documented backend_issue code that nothing could
    deliver. `programs::load_all()` runs at app_main.cpp:58 and
    `web_server::start()` at :76, and `sse_hub::enqueue` returns early while there
    is no server - so a stored program that would not parse was skipped, vanished
    from GET /programs, and left one warning on a serial console nobody at a range
    is watching. Since #80 that is also the migration story for a club-uploaded
    program with a typo in `command`.
    sse_hub now keeps those frames instead of dropping them, and
    GET /api/v2/diagnost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
    [asyncapi.yaml, openapi.yaml]
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2026-08-21 fix(contracts): mark GET /audios as explicitly unauthenticated (#96)
    fix(contracts): mark GET /audios as always unauthenticated
    Its mutating neighbours (POST /audios, POST /audios/{id}/play, DELETE
    /audios/{id}/delete) each carry an explicit `security` block because
    they gate on admin mode. GET /audios never does — web_server.cpp's
    handler never calls require_admin — so it silently relied on the
    global default instead of saying so. Add the explicit `security: -
    {}` to match its neighbours' pattern and make that plain in the spec.
    Generated types are unaffected (openapi-typescript emits the same
    src/api/generated.d.ts before and after), matching the issue. Bumps
    info.version to 2.2.1 pe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
    [openapi.yaml]
2026-08-21 fix(firmware): discard a dead upload instead of refusing the next one (#101)
    The `s_upload_in_flight` guard modelled a situation that cannot occur and
    caused one that can. `ENABLE_ASYNC` is off, so esp_http_server serves one
    request at a time and two audio uploads never overlap; the only way the flag
    was set when a new upload began was a stuck flag from an upload whose
    connection died mid-body, which returns ESP_FAIL out of
    MultipartProcessor::process() and never reaches onRequest - the only reset.
    Vendored _handleUploadByte discards the upload callback's return value, so the
    refusal skipped one 8 KiB chunk rather than the request. A single-chunk clip
    vanished entirely (400 "No file uploade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
    [openapi.yaml]
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2026-08-21 feat(api)!: POST /programs/start carries the program id (D-27) (#106)
    feat(api)!: POST /programs/start carries the program id
    `start` carried no id, so it started whatever the device held when the
    request landed. #92 closed every client-side window - the armed countdown,
    the fire-time re-check against the query cache, the SSE-status guard - and
    none of them can be airtight, because the ambiguity is in the request rather
    than in the client: between a client's last knowledge and its start arriving,
    another client on the range can always load something else. On a range that
    is wrong target timing and wrong spoken range commands.
    The body `{"id": N}` is required, and a device holding a differe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
    [openapi.yaml]
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2026-08-21 feat(api)!: answer every REST error with an RFC 9457 problem detail (D-19) (#111)
    * feat(api)!: answer every REST error with an RFC 9457 problem detail
    Every failure the API answers becomes `application/problem+json` carrying
    `type`, `title`, `status` and `detail` (D-19). `instance` is omitted: it
    identifies one occurrence and the device has no request ids.
    The bug this closes is in `webapp/src/lib/program-notices.ts`, which told the
    two `409`s `PUT /programs/{id}` answers apart by running
    `/read-only|readonly|shipped/i` over the device's English. Rewording either
    sentence silently swapped the two explanations, and neither could ever be
    translated for a Swedish club. Four distinct refusals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
    [asyncapi.yaml, openapi.yaml]
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2026-08-22 feat(firmware): leave the targets showing at boot (#121)
    * feat(firmware): leave the targets showing at boot
    The port hid the targets about a second into boot. The MicroPython backend
    also hid them, but only after loading every program and audio entry, which on
    that runtime took long enough that nobody watched them move. Ported to C++ the
    same hide lands at 984 ms, in plain sight, which read as the firmware having
    inverted the signals.
    It had not: same pin, same polarity, same end state. But moving them at all is
    wrong here, for two reasons that came from the range rather than the code:
    - Face-on is the resting position. The other disciplines shoot these targets
    static, so showing is th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
    [targets.cpp]
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2026-08-23 fix(firmware): separate shipped and uploaded id ranges (#172)
    * fix(firmware): separate shipped and uploaded id ranges (#129)
    kFirstUploadId (100) was meant to keep uploaded programs and audio
    clear of the shipped ones, but resources/programs/files/100.json,
    101.json and the shipped "Beep" audio clip (id 100) sat inside that
    range. Since load_all() loads shipped then uploaded into the same
    map, an uploaded id landing on one of these would silently win,
    masking the shipped entry - exactly what promoting a device-authored
    program into resources/ would trigger.
    Renumber the colliding shipped resources below the upload range, and
    make a same-id collision loud instead of silent: programs::load_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
    [asyncapi.yaml, openapi.yaml]
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2026-08-23 feat(contracts)!: require a program id on skip_to (#186)
    POST /programs/series/{index}/skip_to named a series index but not the
    program, so it acted on whatever the device held when the request
    landed. Mirrors D-27 exactly (#95): the body now requires {"id": N},
    a device holding a different program refuses with 409
    skip_program_mismatch naming both ids, and a malformed or absent body
    is 400 skip_id_required. "Nothing loaded or index out of bounds" stays
    400 series_index_invalid, checked after the id and otherwise
    unchanged. The comparison lives in rt::Executor::skip_to_series under
    the one lock, host-tested the same way start is (D-32).
    reset and stop are deliberately left alone: both are r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
    [openapi.yaml]
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2026-08-23 feat(firmware): update firmware over the air (#190)
    * feat(firmware): update firmware over the air
    Updating meant a USB cable and a laptop with ESP-IDF on it. Now a .bin
    goes up from the Settings page.
    The image is streamed into the inactive app slot, so the running
    firmware is never overwritten, and rollback is already wired: the
    bootloader has CONFIG_BOOTLOADER_APP_ROLLBACK_ENABLE and app_main marks
    the app valid only once it is up. An image that boots but cannot get
    that far is rolled back to the slot it replaced, with no cable involved.
    Three refusals, all in rt_logic where host tests reach them rather than
    buried in an HTTP handler:
    - a program is running. Not 'stop it for them': th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
    [openapi.yaml]
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2026-08-23 feat(firmware): configure the target pin, polarity and hostname without a rebuild (#202)
    * feat(firmware): configure the target pin, polarity and hostname without a rebuild
    First half of #144, which proposes exactly this split: genericise the
    configuration with bank count fixed at one, so it ships without a contract
    change and gives banks somewhere to be configured when they arrive.
    `main/config.h` opens by saying nothing is hardcoded, and that was true - every
    pin and polarity was already a Kconfig symbol. But Kconfig resolves at *build*
    time, so another club could configure this device only by installing ESP-IDF,
    editing sdkconfig and building firmware. From their side that is
    indistingu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
    [hardware_store.cpp, openapi.yaml, targets.cpp]
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2026-08-23 feat(webapp): a Hardware section on Settings, so a club can configure its device (#205)
    * feat(webapp): a Hardware section on Settings, so a club can configure its device
    #202 shipped the API and no way to reach it. The honest answer to "where does
    the user configure their device" was curl or the serial console - neither of
    which is a club member's tool - so the feature existed and nobody could use it.
    Set apart from the rest of Settings on purpose. Every other section is
    recoverable from the page you broke it on; these values are not. A wrong GPIO
    drives nothing, a wrong hostname makes the device hard to find, and the way
    back is a USB cable - which is what configurability was supposed to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
    [audio.cpp, hardware_store.cpp, openapi.yaml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]
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2026-08-24 fix(config): close the gaps a review found in the configuration window (#226)
    #219 guarded `PUT /config/hardware` and left everything around it open.
    **The reset route had no guard at all.** `POST /config/hardware/reset`
    carried only `require_admin`, which returns true when admin mode is off -
    and admin mode is off by default and RAM-only. So the whole protection
    was bypassable in one click, on a route that is *more* destructive than
    any single PUT: it rewrites every value at once, including the hostname
    and pins a non-stock board depends on. Both guards now apply, and two
    tests cover it - checked by reverting the guard and watching them fail.
    **A no-button build ignored the block and clai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
    [boot_button.cpp, openapi.yaml]
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2026-08-25 feat(firmware): a ten-second hold factory-resets the device (#235)
    * feat(firmware): a ten-second hold factory-resets the device
    A device could be onboarded onto a network but never taken off one.
    `wifi_store::clear()` existed and nothing called it: no console command,
    no endpoint, no gesture. Handing a spare board to another club meant it
    joined ours and offered no way in.
    Erasing NVS over USB did not help either, and that is the part worth
    saying out loud: stored credentials are an *overlay*. With NVS empty the
    device falls back to the compiled-in CONFIG_RT_WIFI_SSID seeds, joins,
    and never raises the portal - forcing the portal while testing #217
    needed a throwaway build carrying delibe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
    [boot_button.cpp]
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2026-08-25 feat(firmware): one image, and a partition nothing updates (#239)
    The last stage of #227. The app slots grow 3 MB -> 4.5 MB and carry the
    firmware, the web app and the shipped audio and programs together;
    `storage` is replaced by `userdata`, 6.75 MB of uploads and nothing else,
    which no update path writes. Measured occupancy 3.32 MB of 4.5 MB (72%):
    firmware 1.13, audio 1.96, web app 0.19, programs 0.075.
    One OTA now updates everything, with A/B rollback for all of it inherited
    from the app-slot mechanism rather than built. Version drift between
    firmware and content becomes impossible - one binary, one
    esp_app_desc_t.version - so D-29's single tag stops being a convention
    artifacts can viol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
    [partitions.csv]
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2026-08-25 fix: the paths #239 renamed, everywhere they were left behind (#251)
    #239 moved the mount from `/storage` to `/userdata` and put the shipped
    content in the app image at `/embedded`. It updated the code that reads
    those paths and missed everything that merely *describes* them. Another
    session found the one functional straggler while tracing #250
    (`kStagedUploadPath` in web_server.cpp, fixed separately); this is the
    rest, which is documentation, the contract, and the mock.
    Worst first:
    **firmware/docs/HARDWARE.md gave wrong flash instructions.** It still
    wrote `ota_data_initial.bin` to `0xf000` - the pre-#239 offset, now
    `nvs` - and finished with `0x620000 build/storage.bin`, a file the buil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
    [openapi.yaml]
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2026-08-25 feat(diagnostics): serve the coredump in a bundle, behind the button (#256)
    Getting a crash dump off a board meant a cable, a laptop and an ESP-IDF
    install, and the dump alone was a trap anyway: it decodes only against the
    exact firmware that produced it, and ours reported a SHA mismatch within
    hours because the board had been reflashed.
    `GET /api/v2/diagnostics/bundle` serves a zip holding `diagnostics.json` -
    the `GET /diagnostics/info` body, byte for byte, from the same builder, so
    the file cannot drift from the endpoint it claims to be - and
    `coredump.bin`, the raw partition, when there is one. The diagnostics name
    the build, which is what makes the dump decodable later.
    The gate is th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
    [partitions.csv]
2026-08-25 fix(diagnostics): the bundle is a read, so admin mode does not gate it (#257)
    #256 shipped `GET /diagnostics/bundle` behind `require_admin` as well as the
    configuration window. That was a category error: admin mode is write
    protection - it exists so one operator can run a competition without others
    interfering - not an identity, a role, or a privilege tier. The framing was
    imported from AutoLee, where the password really is authentication; here it
    is an interference lock.
    Behind a read, that lock was wrong in both directions. With admin mode off -
    the default, and the state in which a coredump is actually exposed - it
    protected nothing. With admin mode on, it stopped a club member collectin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
    [openapi.yaml]
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2026-08-26 feat(api)!: rename admin mode to control-lock, everywhere (#267)
    * feat(api)!: rename admin mode to control-lock, everywhere
    "Admin mode" names a role, an identity, a privilege tier. It is none of those:
    it is a lock on *changing* the device, held by whoever is running the exercise.
    docs/site/settings.md already described it correctly - "Full public access"
    against "View only" - and the name said something else.
    That gap is not hypothetical. #256 put GET /diagnostics/bundle - a read -
    behind require_admin, because the word led the author to treat it as
    authentication. It protected nothing in the default state and obstructed a
    fault report in the state where it was on. #257 fixed the endpoi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
    [openapi.yaml]
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2026-09-09 feat(targets): bank model in rt_logic, NVS and the pin driver (#336)
    * feat(targets): bank model in rt_logic, NVS and the pin driver
    Stage 1 of target banks (#207, D-41): a device drives 1..8 independently
    driven target groups, called A to H, instead of one. Firmware only - no
    contract change, no webapp change, and on a one-bank device nothing is
    observable from outside.
    - `rt::TargetBank` and `HardwareConfig::banks` replace the `target_gpio` /
    `target_active_low` scalars. `target_bank.h` carries the shape, the cap,
    the bank mask and `bank_letter()`, which later stages use on the wire.
    - `validate()` runs every bank through the same per-pin checks and detects
    collisions across all ba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
    [hardware_store.cpp, openapi.yaml, targets.cpp]
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
